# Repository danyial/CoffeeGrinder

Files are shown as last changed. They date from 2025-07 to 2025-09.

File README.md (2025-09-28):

# CoffeeGrinder

**Smart coffee grinder controller** with MQTT, OTA updates, and full Home Assistant integration.  
Includes 3D-printable housing, custom PCB (KiCad), and open-source firmware for ESP32.

---

## ✨ Features

- ☕️ Weight-based preset grinding
- 📡 MQTT auto-discovery (Home Assistant integration)
- 🌐 Web interface for configuration
- 🔧 Touch buttons for presets and calibration
- 📊 Live sensor telemetry and control
- 📦 STL files for 3D-printed case
- 🔌 KiCad schematics and PCB

---

## ⚙️ Cycloidal Drive (WIP)

This project uses a custom 3D-printed **cycloidal drive** to reduce the stepper motor's speed and increase torque.  
Currently, this mechanism is still under testing and may change in future iterations.

Contributions, feedback, and test results are welcome!

## 🖼️ Images

<p align="center">
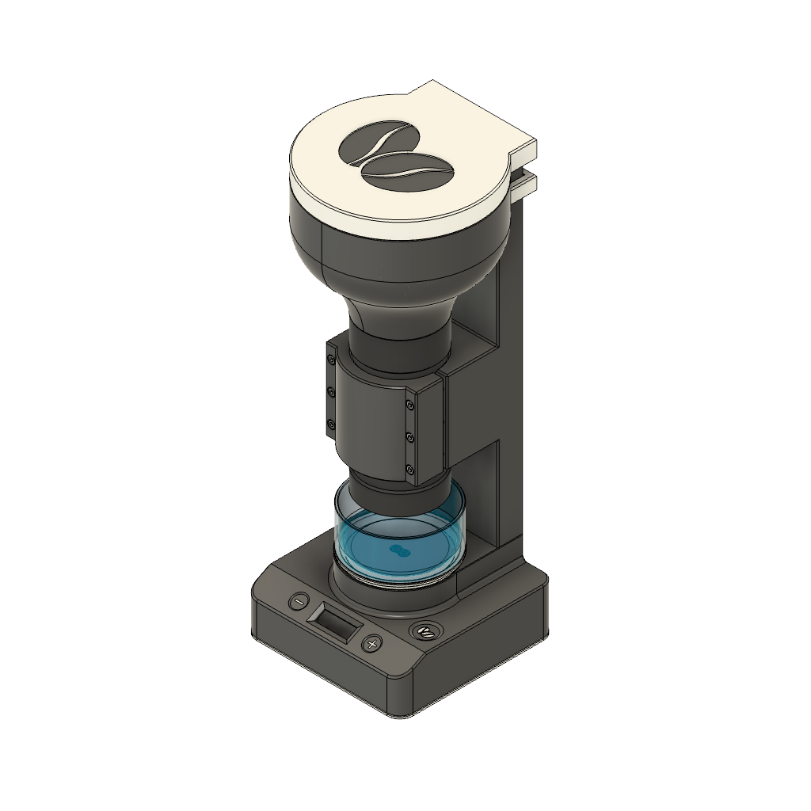
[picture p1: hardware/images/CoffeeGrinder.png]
CoffeeGrinder
  
  <br/>
  <em>CoffeeGrinder assembled</em>
</p>

<p align="center">
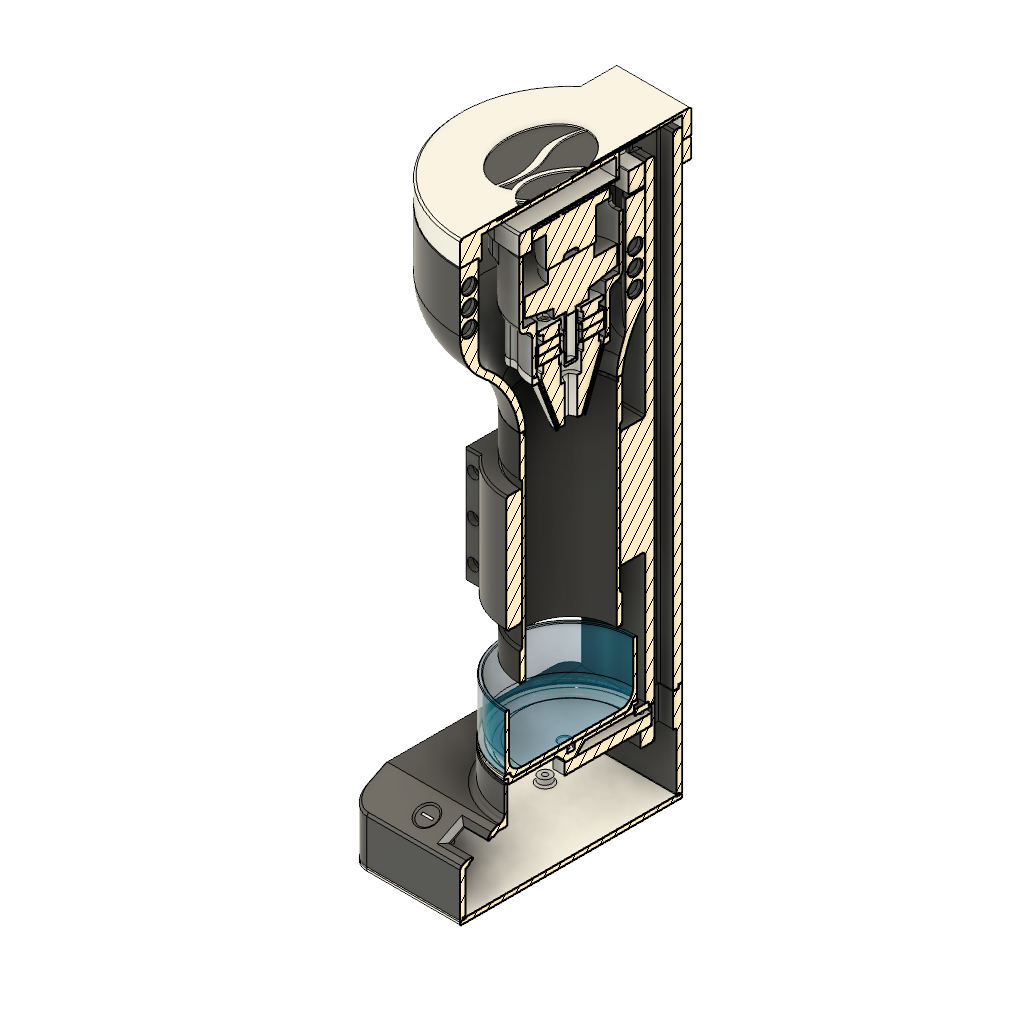
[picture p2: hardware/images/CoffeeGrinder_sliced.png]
CoffeeGrinder Sliced
  
  <br/>
  <em>Section view (sliced)</em>
</p>

<p align="center">
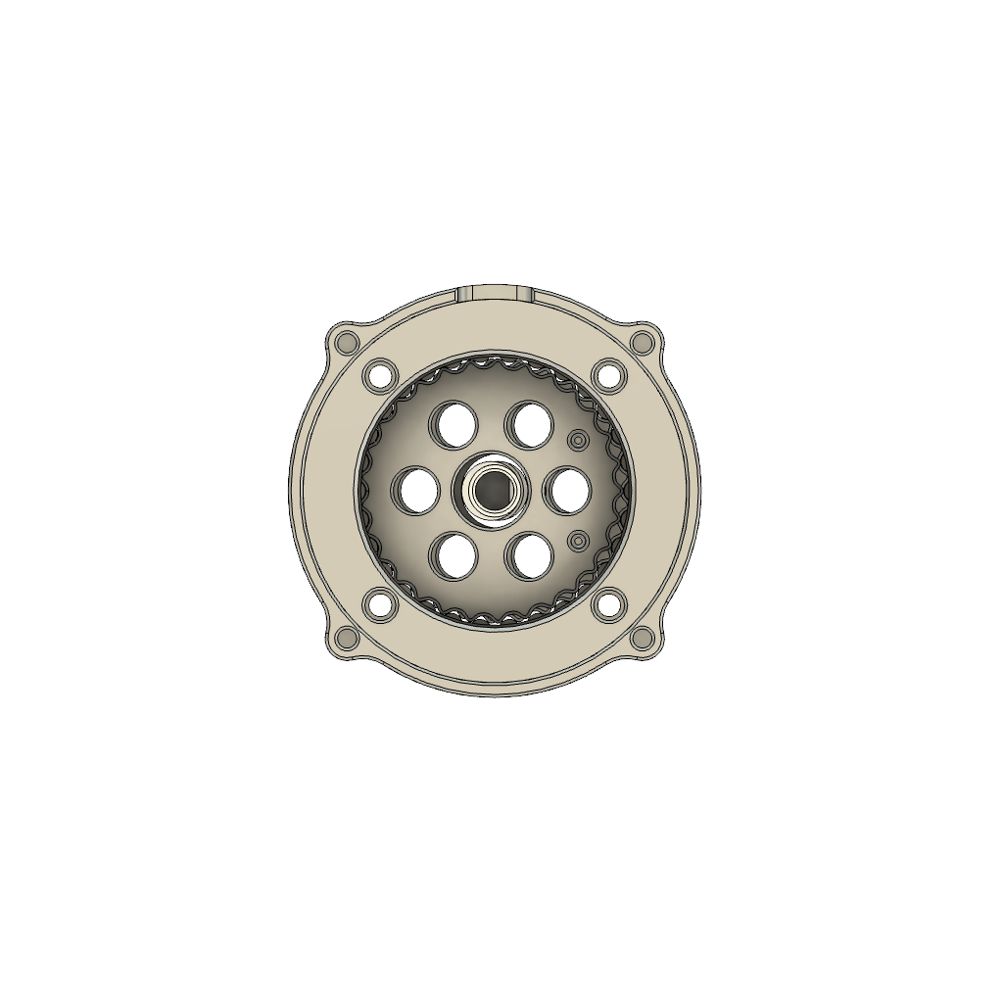
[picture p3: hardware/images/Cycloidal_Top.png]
Cycloidal Drive Top View
  
  <br/>
  <em>Cycloidal Drive Top View</em>
</p>

<p align="center">
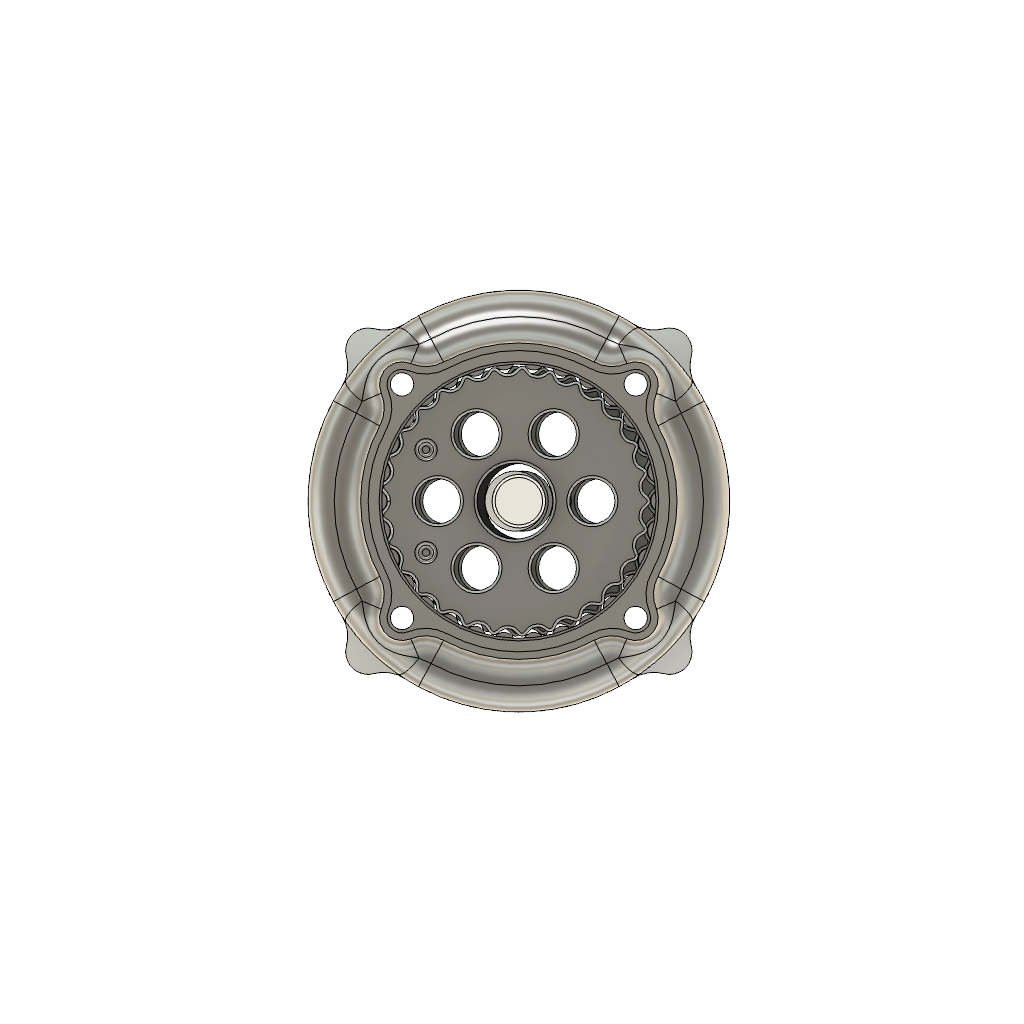
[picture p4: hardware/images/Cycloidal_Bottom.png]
Cycloidal Drive Bottom View
  
  <br/>
  <em>Cycloidal Drive Bottom View</em>
</p>

<p align="center">
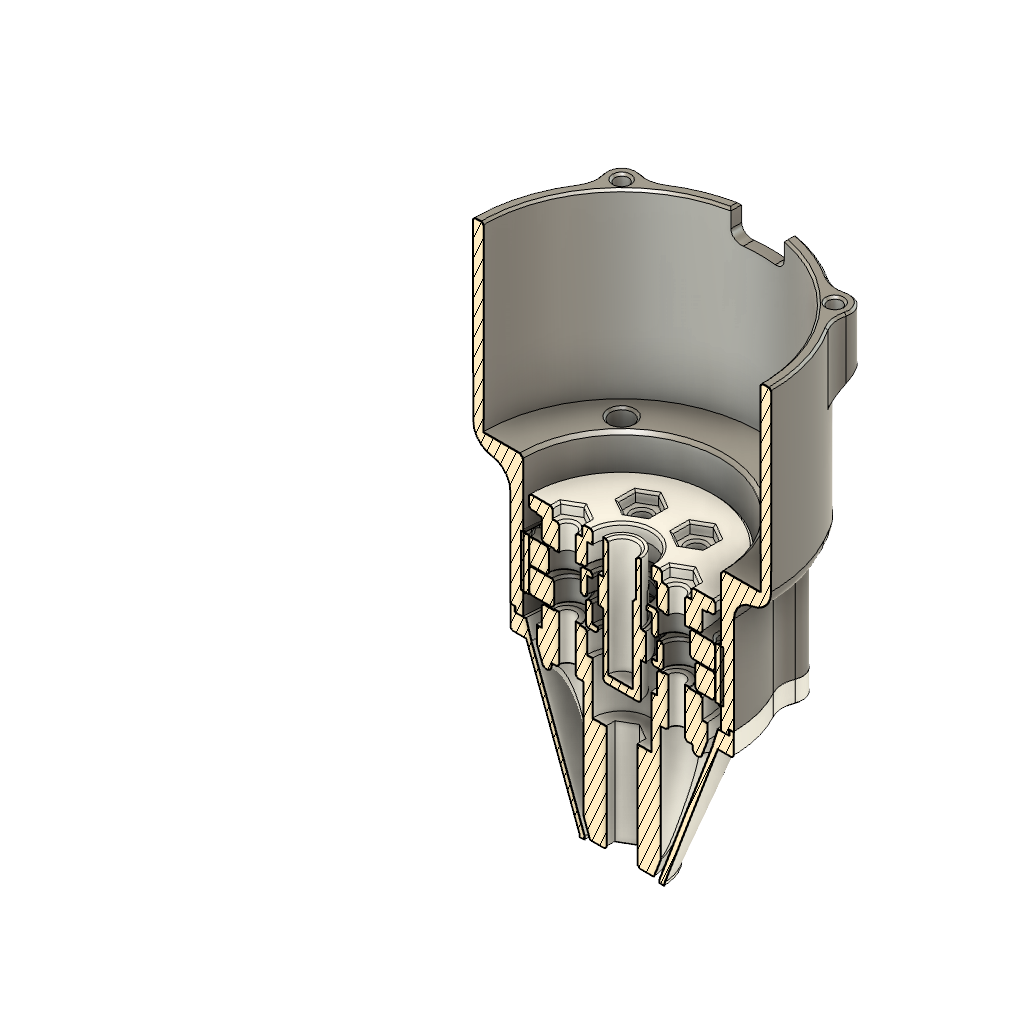
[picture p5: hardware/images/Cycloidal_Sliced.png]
Cycloidal Drive Sliced View
  
  <br/>
  <em>Cycloidal Drive Sliced View</em>
</p>

<p align="center">
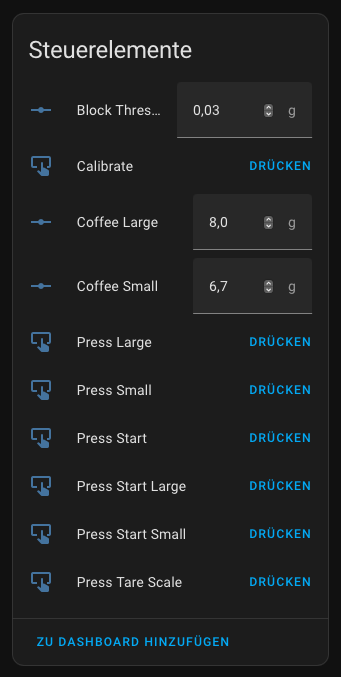
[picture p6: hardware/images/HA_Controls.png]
Home Assistant controls
  
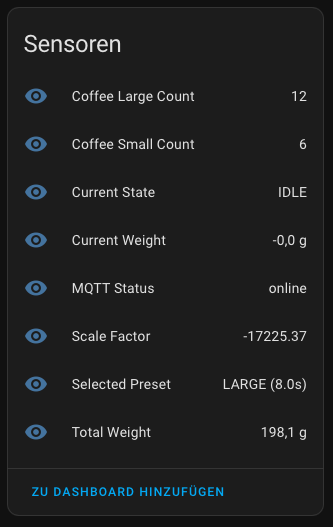
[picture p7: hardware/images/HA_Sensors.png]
Home Assistant sensors
  
  <br/>
  <em>Home Assistant</em>
</p>

---

## 📁 Project Structure

```text
CoffeeGrinder/
├── src/                # Firmware source code
├── include/            # Header files
├── lib/                # Custom libraries (optional)
├── data/               # Web interface (SPIFFS)
├── hardware/
│   ├── stl/            # 3D-printable case parts
│   ├── kicad/          # KiCad PCB project
│   ├── images/         # Project images
│   └── docs/           # Rendered schematics (PDF)
├── docs/               # General project documentation
├── LICENSE.md          # License (AGPL + CC BY-NC-SA)
└── README.md           # This file
```

---

## 🚀 Getting Started

## 🧾 Bill of Materials (BOM)

> **Note**: Some of the links below are affiliate links. If you make a purchase through them, I may receive a small commission at no extra cost to you. Thank you for your support!

- Manual Coffee Grinder [🛒 Amazon](https://amzn.to/4o6IfON)
- ESP32 Dev Board [🛒 Amazon](https://amzn.to/40CVtJ8)
- OLED Display [🛒 Amazon](https://amzn.to/44N8UZx)
- Step Down Converter [🛒 Amazon](https://amzn.to/4o4rhAz)
- HX711 Weight Sensor [🛒 Amazon](https://amzn.to/4lEH1bS)
- Scale [🛒 Amazon](https://amzn.to/3Uswbtt)
- 3x TTP223 Touch Sensors [🛒 Amazon](https://amzn.to/4133kje)
- 3x 10nF Capacitors [🛒 Amazon](https://amzn.to/3IF0UBf)
- Brushless Motor 5010 360KV [🛒 Amazon](https://amzn.to/3VFhHHp)
- ESC 35A or similar (BLHeli_s) - any ESC for brushless motors should work [🛒 Amazon](https://amzn.to/4mAlXCX)
- 2x Bearing 30x37x4 [🛒 Amazon](https://amzn.to/46XXUtu)
- 2x Bearing 8x12x3.5 [🛒 Amazon](https://amzn.to/3UtORsR)
- 2x Bearing 7x13x4 [🛒 Amazon](https://amzn.to/470tUxc)
- 6x Spacer [🛒 Amazon](https://amzn.to/4lLxm3v)
- 12x Magnets 7x2 [🛒 Amazon](https://amzn.to/4f6ZivV)
- Power Supply [🛒 Amazon](https://amzn.to/4o3DJ3y)
- Elko [🛒 Amazon](https://amzn.to/3Uhur6B)
- DC Connector [🛒 Amazon](https://amzn.to/4f7ja2e)
- some cables
- 2x M3x12 SHCS screws [🛒 Amazon](https://amzn.to/4lT12eP)
- 6x M3x16 SHCS screws [🛒 Amazon](https://amzn.to/4lT12eP)
- 6x M3x25 SHCS screws [🛒 Amazon](https://amzn.to/4lT12eP)
- 10x M3x30 SHCS screws [🛒 Amazon](https://amzn.to/4lT12eP)
- 10x M3 screws [🛒 Amazon](https://amzn.to/44Lvy4o)
- 8x M3 nuts [🛒 Amazon](https://amzn.to/4lT12eP)
- 2x M4x20 SHCS screws [🛒 Amazon](https://amzn.to/4lILPgh)
- 6x M3 Threaded Inserts [🛒 Amazon](https://amzn.to/474Kj3K)
- 2x M4 Threaded Inserts [🛒 Amazon](https://amzn.to/44OBxFI)

### Requirements

- MQTT Broker (e.g., Mosquitto)
- Home Assistant (optional, for integration)

### Flashing

Use [PlatformIO](https://platformio.org/) in VSCode:

---

## 🔧 Web Interface

Accessible after WiFi configuration.  
Use it to set:

- MQTT server credentials
- Calibration
- Preset values
- Start grinding manually

---

## 🧠 Home Assistant Integration

Entities auto-discovered via MQTT:

- Sensors: weight, selected preset, scale factor, total weight
- Numbers: block threshold, preset weights
- Buttons: start, calibrate, tare, run preset

Make sure `discovery` is enabled in your MQTT integration.

---

## 🔐 License

- Firmware: [AGPL-3.0](https://www.gnu.org/licenses/agpl-3.0.html)
- Hardware + STL: [CC BY-NC-SA 4.0](https://creativecommons.org/licenses/by-nc-sa/4.0/)

**© 2025 Danny Smolinsky**

For commercial licensing inquiries, contact the author.

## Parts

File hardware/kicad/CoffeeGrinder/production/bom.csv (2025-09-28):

Designator | Footprint | Quantity | Value | LCSC Part #
C1 | CP_Radial_D10.0mm_P7.50mm | 1 | C_Polarized
DISPLAY1 | JST_PH_B4B-PH-K_1x04_P2.00mm_Vertical | 1 | SSD1306
ESC_POWER1 | AMASS_XT30UPB-F_1x02_P5.0mm_Vertical | 1 | Conn_01x02
ESC_SIGNAL1 | JST_PH_B2B-PH-K_1x02_P2.00mm_Vertical | 1 | Conn_01x02_Pin
GRIND1, LED1, LEFT1, RIGHT1 | JST_PH_B3B-PH-K_1x03_P2.00mm_Vertical | 4 | Conn_01x03_Pin
HX711 | JST_PH_B4B-PH-K_1x04_P2.00mm_Vertical | 1 | Conn_01x04_Pin
LM2596 | YAAJ_DCDC_StepDown_LM2596 | 1 | YAAJ_DCDC_StepDown_LM2596
POWER_IN1 | AMASS_XT30UPB-M_1x02_P5.0mm_Vertical | 1 | Conn_01x02_Pin
U1 | ESP32-DevKitC | 1 | ESP32-DevKitC

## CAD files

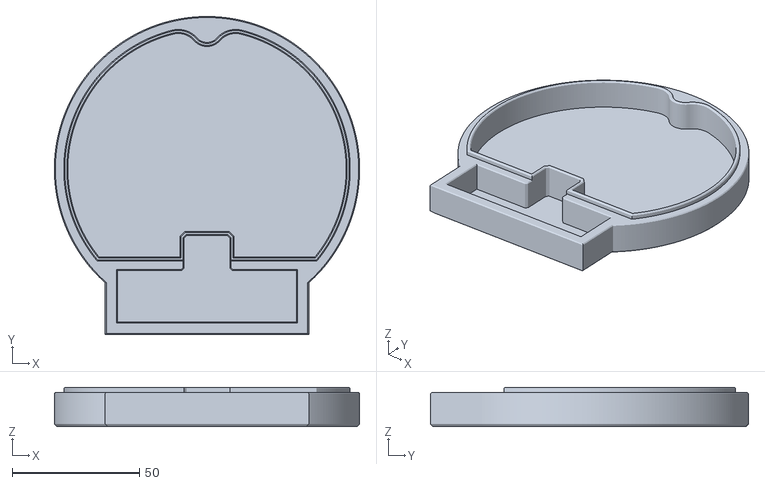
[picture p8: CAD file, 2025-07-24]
hardware/stl/Bean Bucket/Bean Bucked Lid.stl
120.0 x 125.0 x 15.4

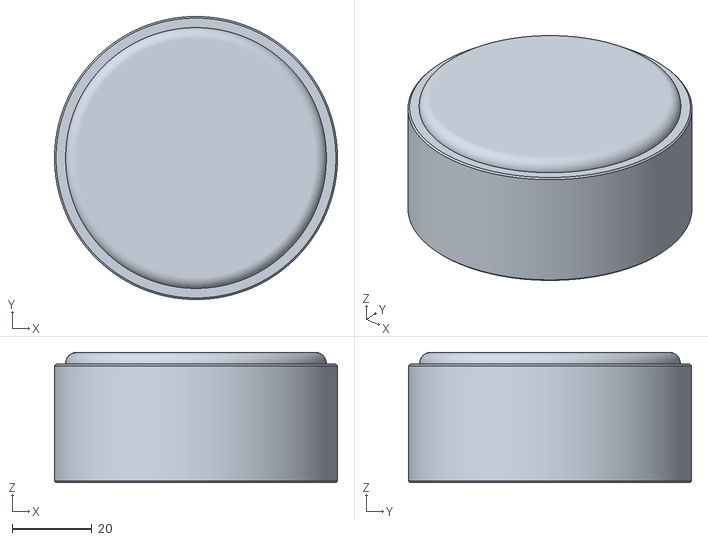
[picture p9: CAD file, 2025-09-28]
hardware/stl/Body/Bowl.stl
71.2 x 71.2 x 32.8

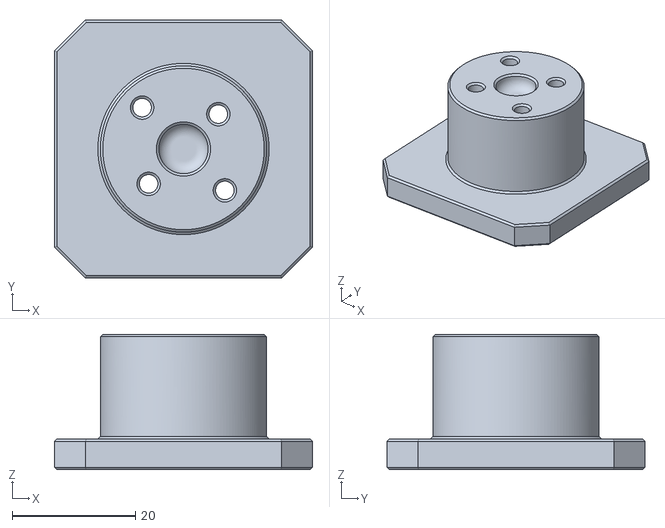
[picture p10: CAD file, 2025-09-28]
hardware/stl/Gear/Motor Mount.stl
41.9 x 41.9 x 22.0

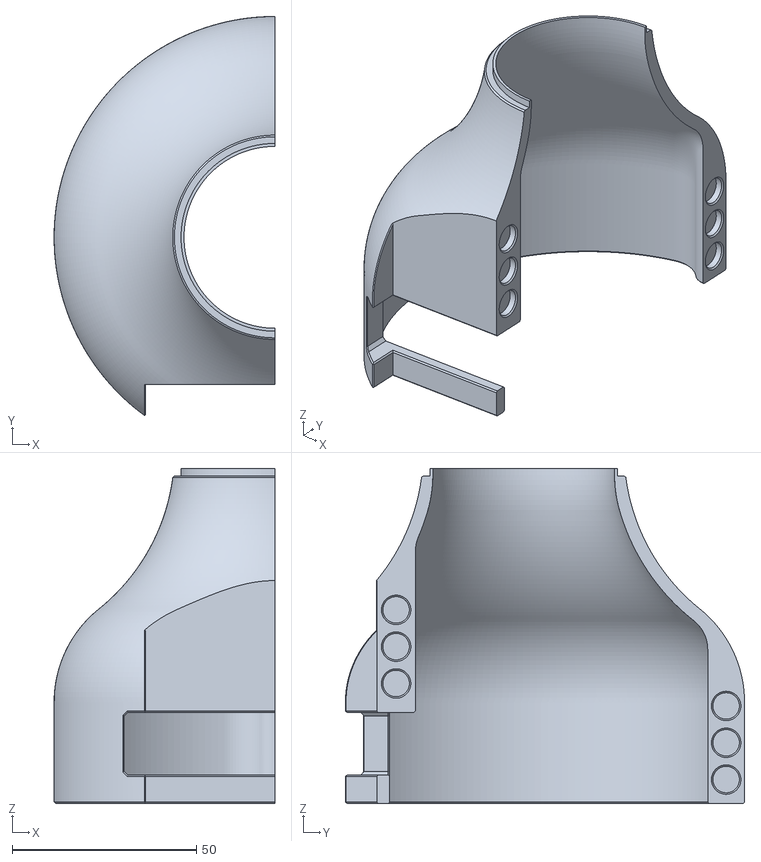
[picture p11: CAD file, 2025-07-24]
hardware/stl/Bean Bucket/Bean Bucket Left.stl
60.0 x 108.4 x 91.0

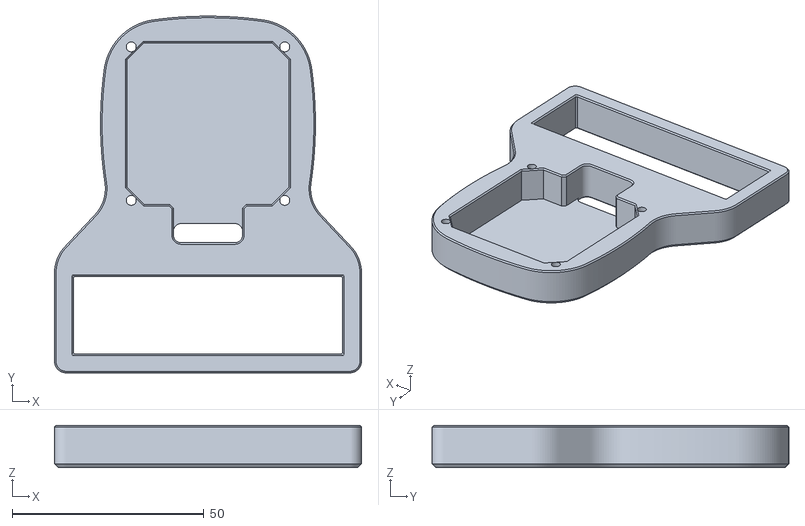
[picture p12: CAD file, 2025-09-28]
hardware/stl/Body/Stepper Fixing.stl
80.0 x 92.9 x 11.0

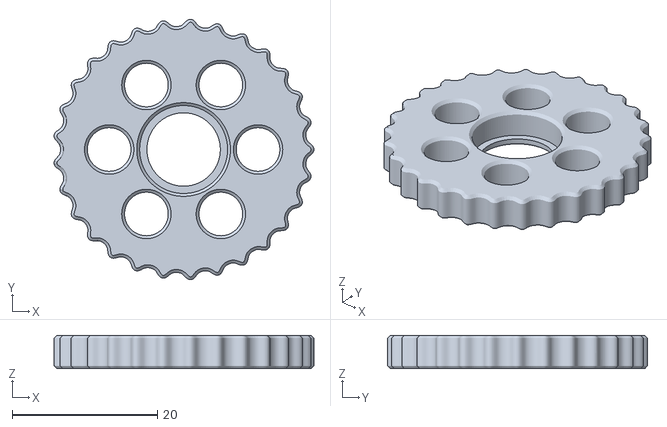
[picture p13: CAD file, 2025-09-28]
hardware/stl/Gear/Disk2 29.stl
35.8 x 35.8 x 4.60

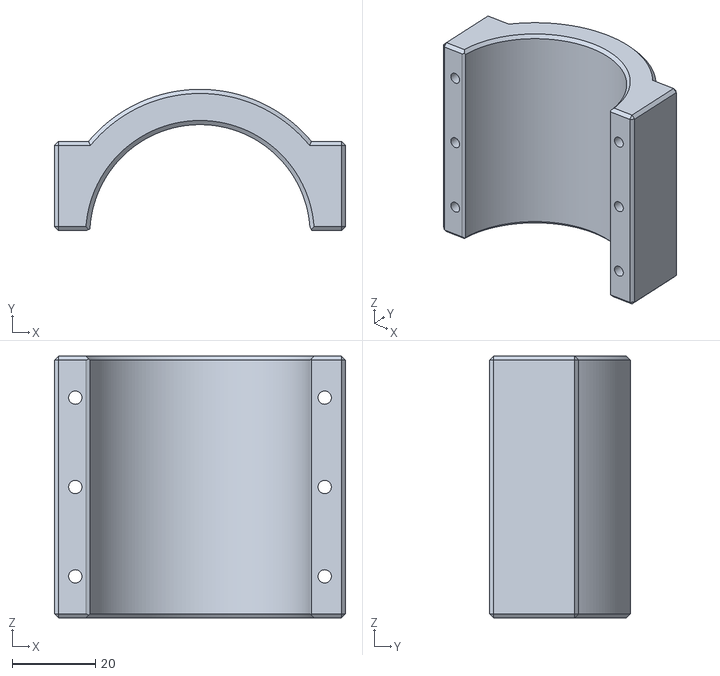
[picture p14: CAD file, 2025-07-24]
hardware/stl/Body/Grinder Holder Front.stl
70.0 x 34.0 x 63.0

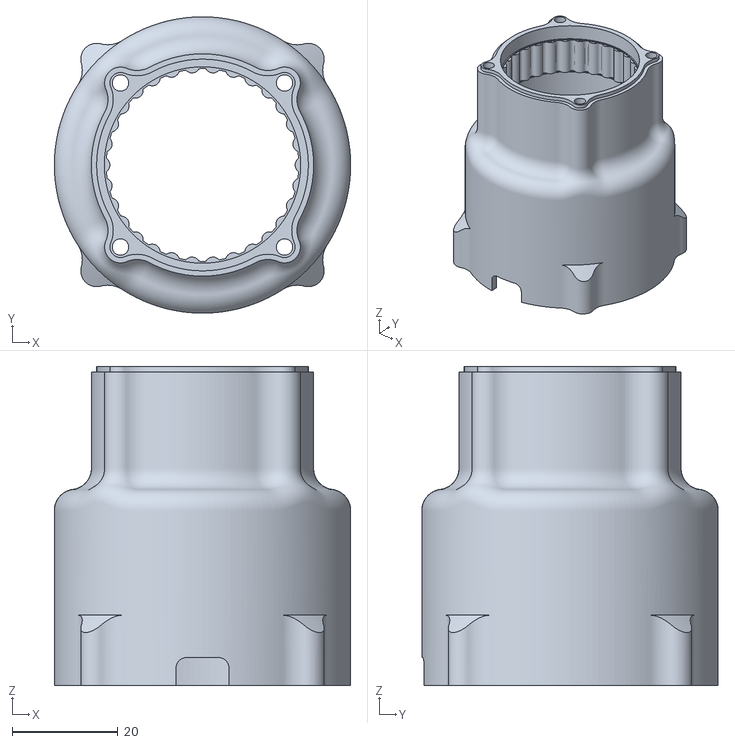
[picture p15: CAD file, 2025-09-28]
hardware/stl/Gear/Housing.stl
56.0 x 56.0 x 60.3

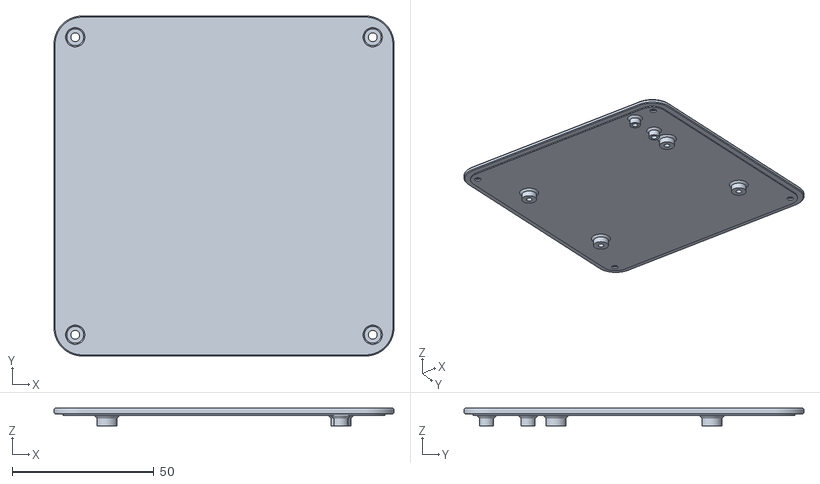
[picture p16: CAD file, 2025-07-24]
hardware/stl/Body/Bottom Plate.stl
120.0 x 120.0 x 6.20

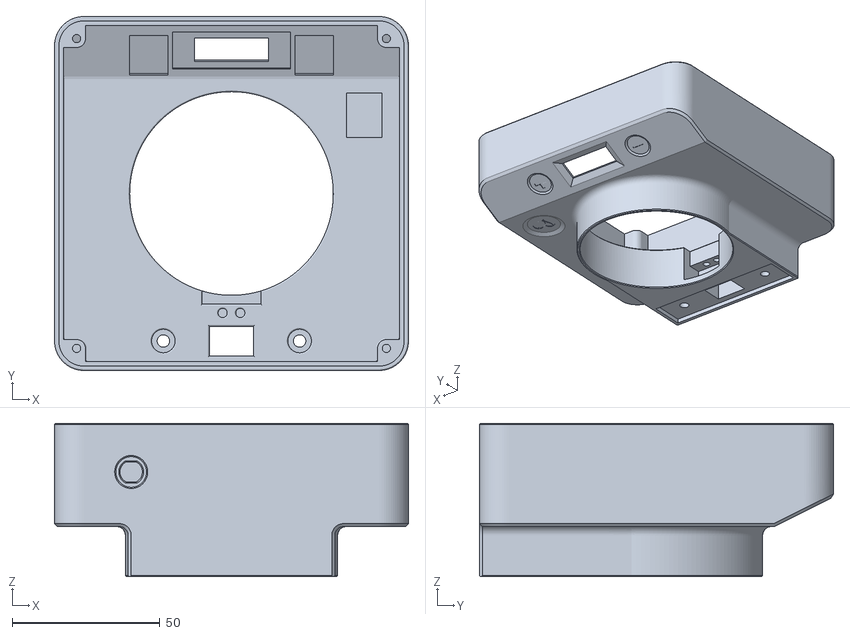
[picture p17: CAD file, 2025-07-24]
hardware/stl/Body/Body.stl
120.0 x 120.0 x 52.0

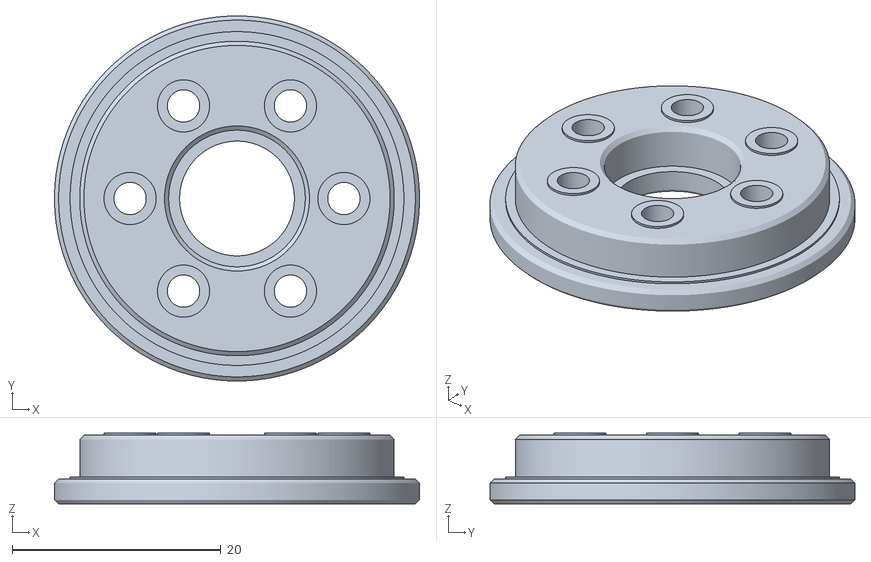
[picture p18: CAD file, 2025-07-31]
hardware/stl/Gear/Cap Top.stl
35.0 x 35.0 x 6.80

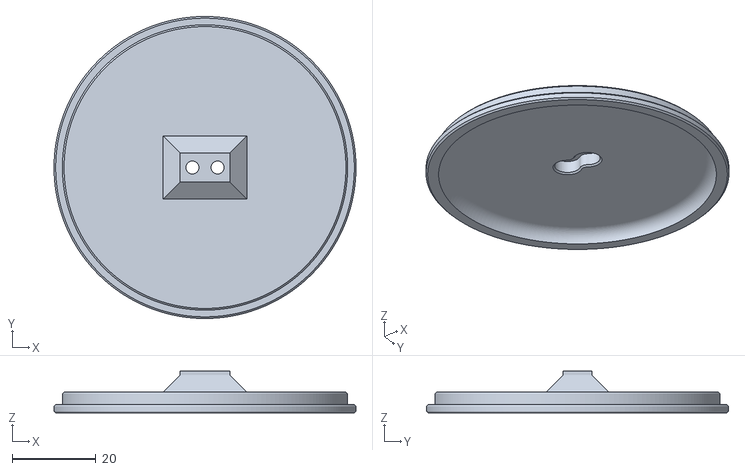
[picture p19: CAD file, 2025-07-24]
hardware/stl/Body/Table.stl
72.0 x 72.0 x 10.0

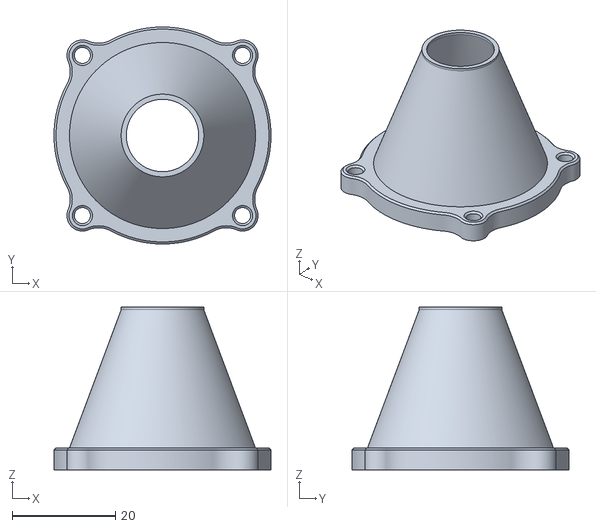
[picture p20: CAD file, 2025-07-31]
hardware/stl/Gear/Coupling Cover.stl
42.0 x 42.0 x 31.5

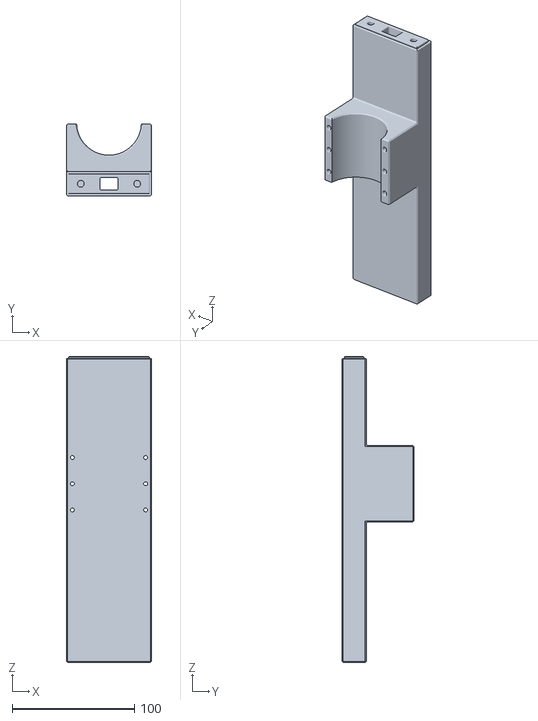
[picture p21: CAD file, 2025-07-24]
hardware/stl/Body/Grinder Holder Back.stl
70.0 x 59.0 x 250.8

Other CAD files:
hardware/stl/Bean Bucket/Bean Bucket Right.stl
hardware/stl/Gear/Disk1 29.stl
hardware/stl/Gear/Cap Bottom.stl
hardware/stl/Gear/Shaft.stl

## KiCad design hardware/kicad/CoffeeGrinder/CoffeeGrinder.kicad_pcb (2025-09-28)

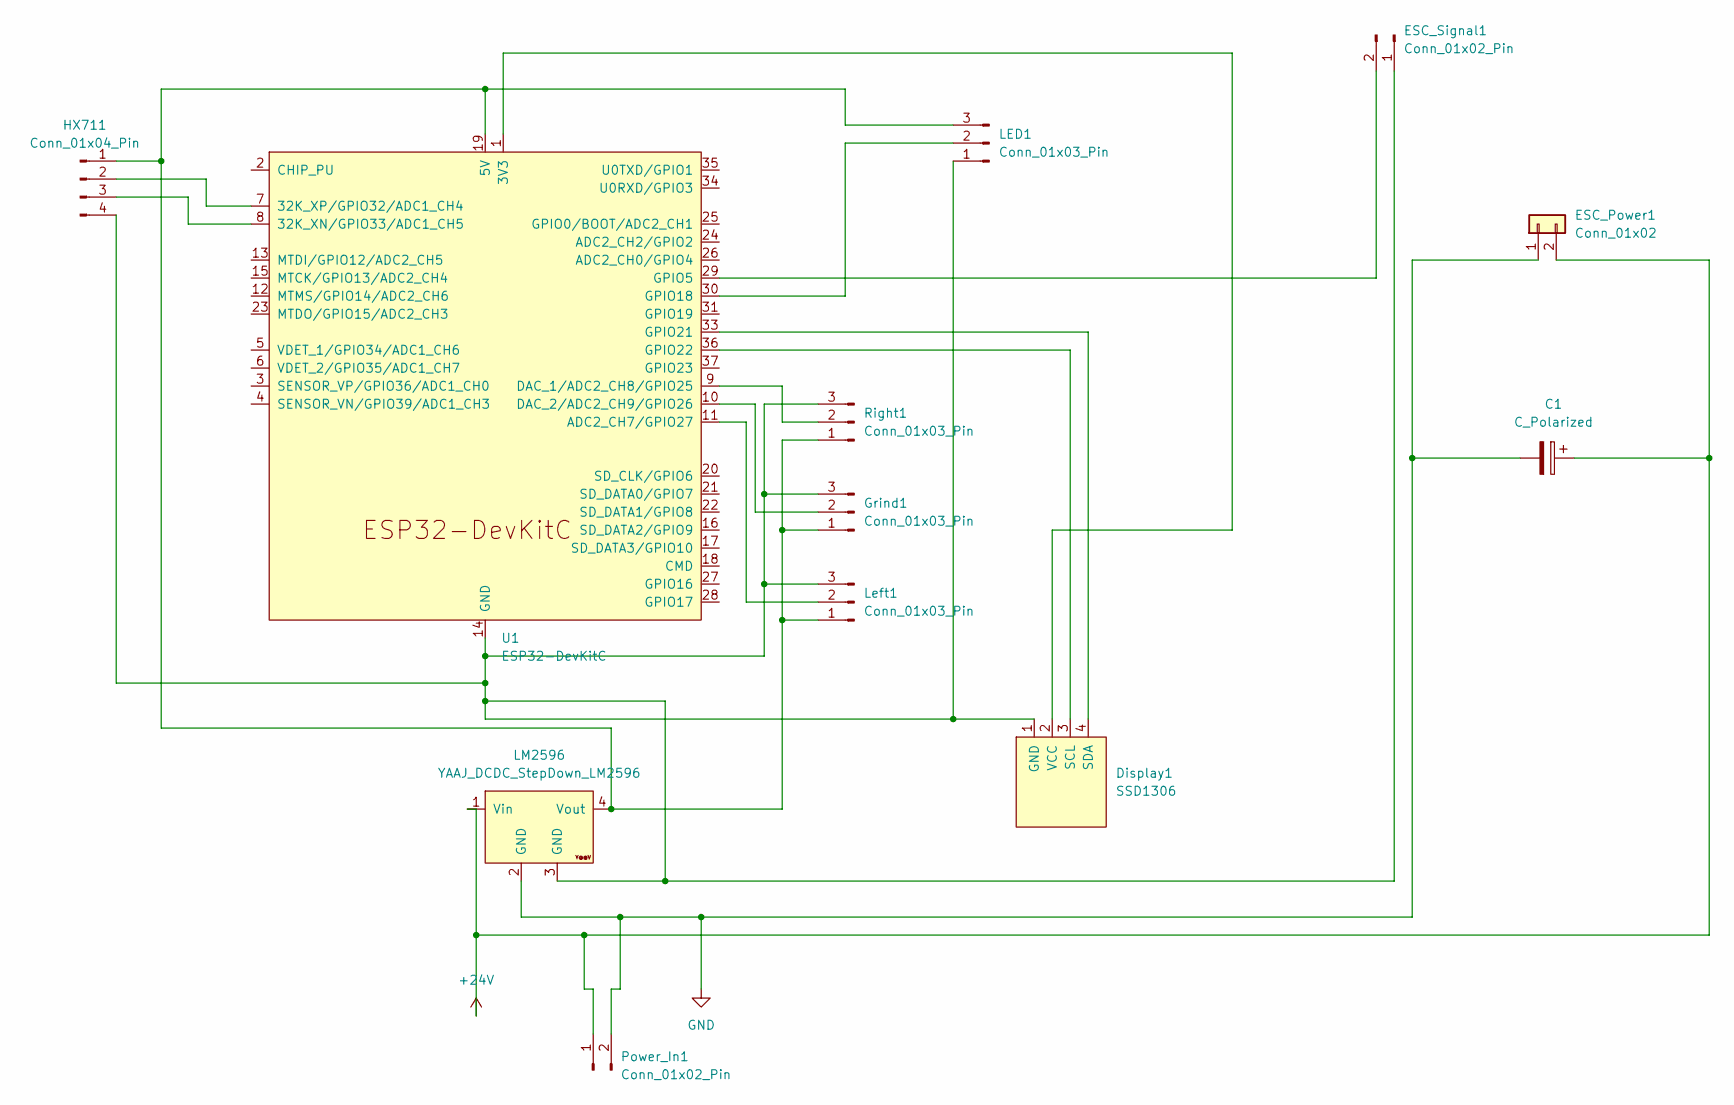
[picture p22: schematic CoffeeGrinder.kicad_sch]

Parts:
C1: C_Polarized; CP_Radial_D10.0mm_P7.50mm
Display1: SSD1306; JST_PH_B4B-PH-K_1x04_P2.00mm_Vertical
ESC_Power1: Conn_01x02; AMASS_XT30UPB-F_1x02_P5.0mm_Vertical
ESC_Signal1: Conn_01x02_Pin; JST_PH_B2B-PH-K_1x02_P2.00mm_Vertical
Grind1: Conn_01x03_Pin; JST_PH_B3B-PH-K_1x03_P2.00mm_Vertical
HX711: Conn_01x04_Pin; JST_PH_B4B-PH-K_1x04_P2.00mm_Vertical
LED1: Conn_01x03_Pin; JST_PH_B3B-PH-K_1x03_P2.00mm_Vertical
LM2596: YAAJ_DCDC_StepDown_LM2596
Left1: Conn_01x03_Pin; JST_PH_B3B-PH-K_1x03_P2.00mm_Vertical
Power_In1: Conn_01x02_Pin; AMASS_XT30UPB-M_1x02_P5.0mm_Vertical
Right1: Conn_01x03_Pin; JST_PH_B3B-PH-K_1x03_P2.00mm_Vertical
U1: ESP32-DevKitC

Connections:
+24V: C1.1, ESC_Power1.2, LM2596.1 (Vin), Power_In1.1
GND: C1.2, ESC_Power1.1, LM2596.2 (GND), Power_In1.2
unnamed: Display1.1 (GND), ESC_Signal1.1, Grind1.3, HX711.4, LED1.1, LM2596.3 (GND), Left1.3, Right1.3, U1.14 (GND), U1.32 (GND), U1.38 (GND)
unnamed: Display1.3 (SCL), U1.36 (GPIO22)
unnamed: Display1.4 (SDA), U1.33 (GPIO21)
unnamed: Display1.2 (VCC), U1.1 (3V3)
unnamed: ESC_Signal1.2, U1.29 (GPIO5)
unnamed: Grind1.1, HX711.1, LED1.3, LM2596.4 (Vout), Left1.1, Right1.1, U1.19 (5V)
unnamed: Grind1.2, U1.10 (DAC_2/ADC2_CH9/GPIO26)
unnamed: HX711.2, U1.7 (32K_XP/GPIO32/ADC1_CH4)
unnamed: HX711.3, U1.8 (32K_XN/GPIO33/ADC1_CH5)
unnamed: LED1.2, U1.30 (GPIO18)
unnamed: Left1.2, U1.11 (ADC2_CH7/GPIO27)
unnamed: Right1.2, U1.9 (DAC_1/ADC2_CH8/GPIO25)

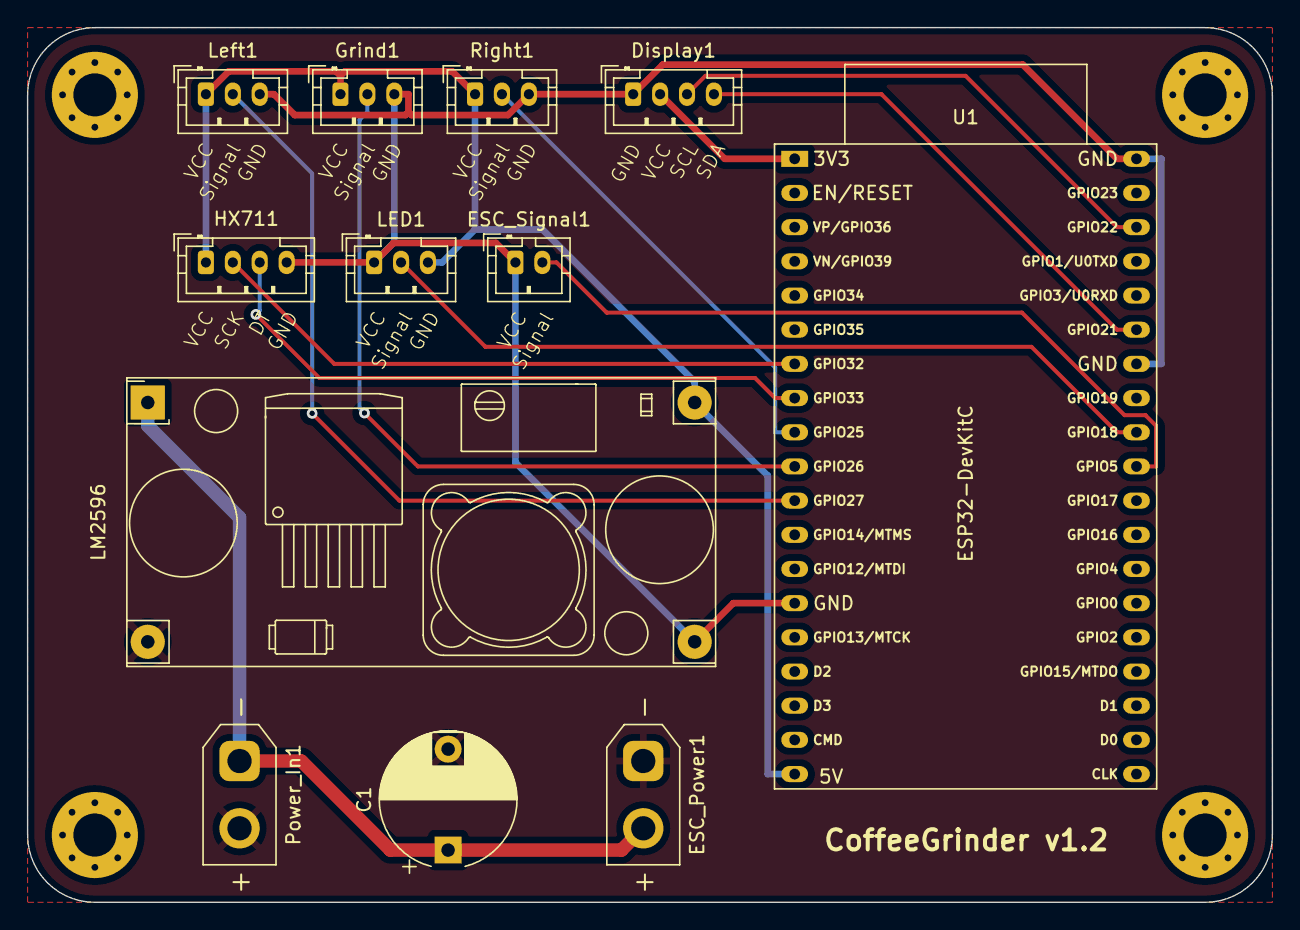
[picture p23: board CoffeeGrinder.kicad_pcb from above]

Board: 2 copper layers, 92.5 x 65.0 mm, 16 parts (0 on the bottom side), 14 nets.

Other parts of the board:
REF1, REF2, REF3, REF4: MountingHole_3.2mm_M3_Pad_Via

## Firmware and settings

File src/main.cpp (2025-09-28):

#include <Arduino.h>
#include <Bounce2.h>
#include <Preferences.h>
#include <WebServer.h>
#include <WiFi.h>
#include <Wire.h>

#include <Adafruit_GFX.h>
#include <Adafruit_SSD1306.h>
#include <DShotRMT.h>
#include <StreamString.h>
#include <esp_wifi.h>

#include <cstdarg>
#include <cstdio>
#include <vector>

#include "HX711.h"
#include "mqtt.h"
#include "ota.h"
#include "pins.h"
#include "types.h"
#include "webserver.h"

// -----------------------------------------------------------------------------
// Configuration constants
// -----------------------------------------------------------------------------

constexpr int8_t OLED_RESET = -1;
constexpr uint8_t SCREEN_ADDRESS = 0x3C;

constexpr unsigned long DISPLAY_REFRESH_MS = 50;
constexpr unsigned long SCALE_INTERVAL_MS = 500;
constexpr unsigned long DEBOUNCE_DELAY = 50;

constexpr uint16_t MIN_PRESET_WEIGHT = 1;
constexpr uint16_t MAX_PRESET_WEIGHT = 300;

constexpr uint16_t MOTOR_RUN_THROTTLE = 1200;
constexpr uint16_t MOTOR_SLOW_THROTTLE = MOTOR_RUN_THROTTLE / 2;
constexpr uint16_t MOTOR_RAMP_UP_STEP = 2;
constexpr uint16_t MOTOR_RAMP_UP_DELAY_MS = 4;
constexpr uint16_t MOTOR_RAMP_DOWN_STEP = 25;
constexpr uint16_t MOTOR_RAMP_DOWN_DELAY_MS = 4;
constexpr uint16_t MOTOR_RAMP_MIN_HOLD_MS = 200;
constexpr float MOTOR_SLOWDOWN_THRESHOLD_G = 0.7f;

const unsigned long LONGPRESS_MS = 2000;

// -----------------------------------------------------------------------------
// Logging
// -----------------------------------------------------------------------------

WiFiServer logServer(23);
std::vector<WiFiClient> clients;

#if ENABLE_LOGGING
static void purgeClients()
{
    for (auto it = clients.begin(); it != clients.end();)
    {
        if (!it->connected())
        {
            it->stop();
            it = clients.erase(it);
        }
        else
        {
            ++it;
        }
    }
}

void logPrint()
{
    Serial.println();
    purgeClients();
    for (auto &client : clients)
    {
        client.println();
    }
}

void logPrint(const String &msg)
{
    Serial.println(msg);
    purgeClients();
    for (auto &client : clients)
    {
        client.println(msg);
    }
}

void logPrint(const __FlashStringHelper *msg)
{
    logPrint(String(msg));
}

void logPrint(const char *msg)
{
    logPrint(String(msg));
}

void logPrintf(const char *fmt, ...)
{
    char buffer[256];
    va_list args;
    va_start(args, fmt);
    int len = vsnprintf(buffer, sizeof(buffer), fmt, args);
    va_end(args);

    if (len < 0)
    {
        return;
    }

    if (len >= static_cast<int>(sizeof(buffer)))
    {
        len = sizeof(buffer) - 1;
    }

    Serial.write(reinterpret_cast<const uint8_t *>(buffer), len);

    purgeClients();
    for (auto &client : clients)
    {
        client.write(reinterpret_cast<const uint8_t *>(buffer), len);
    }
}
#endif

// -----------------------------------------------------------------------------
// Hardware instances
// -----------------------------------------------------------------------------

Bounce2::Button btnStart, btnL, btnR;

Adafruit_SSD1306 display(128, 32, &Wire, OLED_RESET);

DShotRMT motor(PIN_ESC, dshot_mode_t::DSHOT300, false);
static volatile uint16_t throttleStream = DSHOT_THROTTLE_MIN;
static volatile bool stopPending = true;
static uint16_t motorCurrentThrottle = DSHOT_CMD_MOTOR_STOP;

HX711 scale;

// -----------------------------------------------------------------------------
// Runtime state
// -----------------------------------------------------------------------------

volatile State state = IDLE;

uint16_t presetSmall = 8;
uint16_t presetLarge = 12;
PresetSelection selectedPreset = SMALL;

Preferences prefs;

float scaleFactor = 1.0;

uint16_t remaining = 0;
unsigned long lastMillis = 0;
unsigned long lastScaleMillis = 0;

float weight = 0.0;
float lastWeight = 0.0;
unsigned long lastWeightChangeTime = 0;
float blockThreshold = 0.03f;

unsigned long presetSmallRuns = 0;
unsigned long presetLargeRuns = 0;
float totalWeight = 0.0;

bool webStart = false;

// -----------------------------------------------------------------------------
// Forward declarations
// -----------------------------------------------------------------------------

static void motorSendRaw(uint16_t value);
void motorRampTo(uint16_t targetThrottle, uint16_t stepSize, uint16_t delayMs);
inline void motorRampUp() { motorRampTo(MOTOR_RUN_THROTTLE, MOTOR_RAMP_UP_STEP, MOTOR_RAMP_UP_DELAY_MS); }
inline void motorRampDown() { motorRampTo(DSHOT_CMD_MOTOR_STOP, MOTOR_RAMP_DOWN_STEP, MOTOR_RAMP_DOWN_DELAY_MS); }

void setupButtons();
void setupMotor();

void setSelectedPreset(PresetSelection selection);
void setRemainingTime();
void setPreset(PresetSelection selection);
void setState(State s);
void tareScale();
void calibrateScale();
void startGrinding(bool tare);
void enterSetting(PresetSelection selection);
void adjustSetting(State s, int8_t delta);
void handleStartButton(Bounce2::Button button);
void handleButton(Bounce2::Button button, PresetSelection selection);

void loadPreferences();
void savePreferences();

void drawDisplay();
String stateToString(State s);
void logState();

void displayTask(void *pvParameters);
void scaleTask(void *pvParameters);
void mqttTask(void *pvParameters);
void throttleTask(void *pvParameters);

void setup();
void loop();

// -----------------------------------------------------------------------------
// Motor control
// -----------------------------------------------------------------------------

static void motorSendRaw(uint16_t value) {
    if (value == DSHOT_CMD_MOTOR_STOP) {
        motorCurrentThrottle = DSHOT_CMD_MOTOR_STOP;
        stopPending = true;
        throttleStream = DSHOT_THROTTLE_MIN; // Signal am Leben halten
        return;
    }
    uint16_t constrained = constrain(value, DSHOT_THROTTLE_MIN, DSHOT_THROTTLE_MAX);
    motorCurrentThrottle = constrained;
    throttleStream = constrained;
}

void motorRampTo(uint16_t targetThrottle, uint16_t stepSize, uint16_t delayMs)
{
    uint16_t currentThrottle = motorCurrentThrottle;
    uint16_t desired = targetThrottle;

    if (desired == DSHOT_CMD_MOTOR_STOP)
    {
        if (currentThrottle == DSHOT_CMD_MOTOR_STOP)
        {
            throttleStream = DSHOT_THROTTLE_MIN;
            return;
        }

        int32_t value = currentThrottle;
        int32_t step = stepSize ? stepSize : 1;
        while (value > DSHOT_THROTTLE_MIN)
        {
            value -= step;
            if (value < DSHOT_THROTTLE_MIN)
            {
                value = DSHOT_THROTTLE_MIN;
            }

            motorSendRaw(static_cast<uint16_t>(value));
            if (delayMs)
            {
                delay(delayMs);
            }
        }

        motorSendRaw(DSHOT_CMD_MOTOR_STOP);
        return;
    }

    if (desired < DSHOT_THROTTLE_MIN)
    {
        desired = DSHOT_THROTTLE_MIN;
    }

    if (currentThrottle == desired)
    {
        motorSendRaw(desired);
        return;
    }

    int32_t step = stepSize ? stepSize : 1;
    step = (desired > currentThrottle) ? step : -step;
    if (step == 0)
    {
        step = (desired > motorCurrentThrottle) ? 1 : -1;
    }

    int32_t value = currentThrottle;
    bool minHoldDone = false;

    while (value != desired)
    {
        value += step;

        if ((step > 0 && value > desired) || (step < 0 && value < desired))
        {
            value = desired;
        }

        if (value < DSHOT_THROTTLE_MIN)
        {
            value = DSHOT_THROTTLE_MIN;
        }

        motorSendRaw(static_cast<uint16_t>(value));

        if (!minHoldDone && value == DSHOT_THROTTLE_MIN && desired > DSHOT_THROTTLE_MIN && MOTOR_RAMP_MIN_HOLD_MS > 0)
        {
            delay(MOTOR_RAMP_MIN_HOLD_MS);
            minHoldDone = true;
        }

        if (delayMs)
        {
            delay(delayMs);
        }
    }
}

// -----------------------------------------------------------------------------
// Input hardware
// -----------------------------------------------------------------------------

// Configure button pins and debounce settings
void setupButtons()
{
    btnStart.attach(BTN_START, INPUT);
    btnStart.interval(DEBOUNCE_DELAY);
    btnStart.setPressedState(HIGH);

    btnR.attach(BTN_R, INPUT);
    btnR.interval(DEBOUNCE_DELAY);
    btnR.setPressedState(HIGH);

    btnL.attach(BTN_L, INPUT);
    btnL.interval(DEBOUNCE_DELAY);
    btnL.setPressedState(HIGH);
}

// Setup motor
void setupMotor()
{
    // Initialize the motor
    dshot_result_t result = motor.begin();
    if (result.success) {
        LOG("Motor initialized successfully");
    } else {
        printDShotResult(result);
    }
}

// -----------------------------------------------------------------------------
// Grinding workflow & state transitions
// -----------------------------------------------------------------------------

// Setter for selected preset without side effects
void setSelectedPreset(PresetSelection selection)
{
    selectedPreset = selection;
}

// Set remaining time based on selected preset
void setRemainingTime()
{
    LOGF("[REMAINING] %.1fg / %.1fg\n", presetSmall / 10.0, presetLarge / 10.0);
    remaining = (selectedPreset == SMALL) ? presetSmall : presetLarge;
}

void setPreset(PresetSelection selection)
{
    setSelectedPreset(selection);
    savePreferences();
    setState(IDLE);
    scale.tare();
}

// Setter for state variable with automatic logging
void setState(State s)
{
    state = s;
    logState();
}

void tareScale()
{
    LOG("Tare Scale");
    delay(500);
    scale.tare();
}

void calibrateScale()
{
    setState(CALIBRATE);

    LOG("== SCALE CALIBRATION ==");
    LOG("Remove all weight. Taring...");
    scale.tare();
    LOG("Place known weight (e.g. 100g) and press Start button.");
}

// Start grinding: reset timer, optionally tare scale and change state to RUNNING
void startGrinding(bool tare)
{
    if (state == IDLE && tare)
    {
        tareScale();
    }

    lastMillis = millis();
    setRemainingTime();
    setState(RUNNING);
}

// Enter setting mode for selected preset
void enterSetting(PresetSelection selection)
{
    setState(selection == SMALL ? SET_LEFT : SET_RIGHT);
}

// Adjust preset time in setting mode
void adjustSetting(State s, int8_t delta)
{
    if (s == SET_LEFT)
        presetSmall += delta;
    else
        presetLarge += delta;
    presetSmall = constrain(presetSmall, MIN_PRESET_WEIGHT, MAX_PRESET_WEIGHT);
    presetLarge = constrain(presetLarge, MIN_PRESET_WEIGHT, MAX_PRESET_WEIGHT);
}

// Handle button press for short and long press actions
void handleStartButton(Bounce2::Button button)
{
    static bool isSetWeighing = false;
    static bool isSetIdle = false;

    if (button.isPressed())
    {
        if (button.currentDuration() >= LONGPRESS_MS)
        {
            if (state == IDLE && !isSetIdle)
            {
                isSetWeighing = true;
                setState(WEIGHING);
                tareScale();
            }
            else if (state == WEIGHING && !isSetWeighing)
            {
                isSetIdle = true;
                setState(IDLE);
            }
        }
    }
    else if (button.released())
    {
        LOG("RELEASED");
        if (button.currentDuration() < LONGPRESS_MS)
        {
            LOG("SHORT");
            if (state == IDLE && !isSetIdle)
            {
                LOG("Start Grinding");
                startGrinding(true);
                lastWeight = weight;
            }
            else if (state == WEIGHING && !isSetWeighing)
            {
                tareScale();
            }
        }

        isSetIdle = false;
        isSetWeighing = false;
    }
}

void handleButton(Bounce2::Button button, PresetSelection selection)
{
    static bool isSetSettings = false;

    if (button.isPressed())
    {
        if (button.currentDuration() >= LONGPRESS_MS && !isSetSettings)
        {
            LOG("Enter Settings");
            isSetSettings = true;
            enterSetting(selection);
        }
    }

    if (button.released())
    {
        if (button.currentDuration() < LONGPRESS_MS)
        {
            LOG("Set Preset");
            setPreset(selection);
        }

        isSetSettings = false;
    }
}

// -----------------------------------------------------------------------------
// Preferences & persistence
// -----------------------------------------------------------------------------

// Load presets and selected preset from non-volatile storage
void loadPreferences()
{
    prefs.begin("coffee", false);

    presetSmall = prefs.getUShort("pL", 8 * 10);
    presetLarge = prefs.getUShort("pR", 12 * 10);

    LOGF("[PREFERENCES] %d / %d g\n", presetSmall, presetLarge);

    uint32_t sel = prefs.getUInt("sel", static_cast<uint32_t>(selectedPreset));
    selectedPreset = (sel <= LARGE) ? static_cast<PresetSelection>(sel) : SMALL;

    scaleFactor = prefs.getFloat("scale", 1.0);
    scale.set_scale(scaleFactor);

    totalWeight = prefs.getFloat("totalWeight", 0.0);
    presetSmallRuns = prefs.getULong("presetSmallRuns", 0);
    presetLargeRuns = prefs.getULong("presetLargeRuns", 0);
    blockThreshold = prefs.getFloat("blockThreshold", 0.3);

    prefs.end();
}

// Save presets and selected preset to non-volatile storage
void savePreferences()
{
    prefs.begin("coffee", false);

    prefs.putUShort("pL", presetSmall);
    prefs.putUShort("pR", presetLarge);
    prefs.putUInt("sel", static_cast<uint32_t>(selectedPreset));
    prefs.putFloat("scale", scaleFactor);
    prefs.putFloat("totalWeight", totalWeight);
    prefs.putULong("presetSmallRuns", presetSmallRuns);
    prefs.putULong("presetLargeRuns", presetLargeRuns);
    prefs.putFloat("blockThreshold", blockThreshold);

    prefs.end();

    setSelectedPreset(selectedPreset);
    setRemainingTime();
    drawDisplay();
}

// -----------------------------------------------------------------------------
// Display & logging
// -----------------------------------------------------------------------------

// Update OLED display based on current state
void drawDisplay()
{
    display.clearDisplay();
    char buf[32];
    switch (state)
    {
    case IDLE:
        sprintf(buf, "%4.1fg", (selectedPreset == SMALL ? presetSmall : presetLarge) / 10.0);
        break;
    case WEIGHING:
        sprintf(buf, "%4.1fg", weight);
        break;
    case RUNNING:
        // float weight = scale.get_units();
        sprintf(buf, "%4.1fg", (remaining / 10.0) - weight);
        break;
    case PAUSED:
        sprintf(buf, "%4.1fg", (remaining / 10.0) - weight);
        break;
    case MEASURING:
        sprintf(buf, "Warte...");
        break;
    case FINISHED:
        sprintf(buf, "Fertig!");
        break;
    case SAVING:
        sprintf(buf, "Gespeichert!");
        break;
    case SET_LEFT:
        sprintf(buf, "Setze Kl.: %4.1f%s", presetSmall / 10.0, "g");
        break;
    case SET_RIGHT:
        sprintf(buf, "Setze Gr.: %4.1f%s", presetLarge / 10.0, "g");
        break;
    case CALIBRATE:
        sprintf(buf, "Kalibrierung");
        break;
    case EMPTY:
        sprintf(buf, "Bohnen\nleer?");
        break;
    case UPDATING:
        sprintf(buf, "Update...");
        break;
    }

    int16_t x1, y1;
    uint16_t w, h;
    display.setTextSize(2);
    display.getTextBounds(buf, 0, 0, &x1, &y1, &w, &h);
    int16_t x = (display.width() - w) / 2;
    int16_t y = (display.height() - h) / 2;
    display.setCursor(x, y);
    display.setTextColor(SSD1306_WHITE);
    display.println(buf);
    display.display();
}

// Convert state enum to human-readable string
String stateToString(State s)
{
    switch (s)
    {
    case IDLE: return "IDLE";
    case RUNNING: return "RUNNING";
    case PAUSED: return "PAUSED";
    case MEASURING: return "MEASURING";
    case FINISHED: return "FINISHED";
    case SAVING: return "SAVING";
    case SET_LEFT: return "SET_LEFT";
    case SET_RIGHT: return "SET_RIGHT";
    case CALIBRATE: return "CALIBRATE";
    case UPDATING: return "UDATING";
    case EMPTY: return "EMPTY";
    case WEIGHING: return "WEIGHING";
    default: return "UNKNOWN";
    }
}

// Log current state, preset and remaining time
void logState()
{
    LOGF("[STATE] %s\n", stateToString(state));
    LOGF("[PRESET] %s\n", (selectedPreset == SMALL) ? "SMALL" : "LARGE");
    LOGF("[REMAINING] %.1fg\n", remaining / 10.0);
}

// -----------------------------------------------------------------------------
// FreeRTOS tasks
// -----------------------------------------------------------------------------

// FreeRTOS task to refresh the display periodically
void displayTask(void *pvParameters)
{
    (void)pvParameters;
    while (true)
    {
        drawDisplay();
        vTaskDelay(pdMS_TO_TICKS(DISPLAY_REFRESH_MS));
    }
}

void scaleTask(void *pvParameters)
{
    (void)pvParameters;
    while (true)
    {
        weight = scale.get_units();
        // LOGF("[SCALE - Task] %.2f g\n", weight);
        vTaskDelay(pdMS_TO_TICKS(200));
    }
}

void mqttTask(void *pvParameters)
{
    (void)pvParameters;
    while (true)
    {
        loopMqtt();
        mqttPublishState();
        vTaskDelay(pdMS_TO_TICKS(100));
    }
}

void throttleTask(void *) {
    const TickType_t interval = pdMS_TO_TICKS(1);
    while (true) {
        if (stopPending) {
            motor.sendThrottle(DSHOT_CMD_MOTOR_STOP); // Befehl einmal
            stopPending = false;
        } else {
            motor.sendThrottle(throttleStream);       // Idle oder Run
        }
        vTaskDelay(interval);
    }
}

// -----------------------------------------------------------------------------
// Arduino lifecycle
// -----------------------------------------------------------------------------
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
void loop()
{
    ArduinoOTA.handle();

    WiFiClient newClient = logServer.accept();
    if (newClient)
    {
        newClient.setNoDelay(true);
        clients.push_back(newClient);
    }

    unsigned long now = millis();

    btnStart.update();
    btnL.update();
    btnR.update();

    if (now - lastScaleMillis >= SCALE_INTERVAL_MS && state != CALIBRATE)
    {
        lastScaleMillis += SCALE_INTERVAL_MS;
        // LOGF("[SCALE - loop] %.2f g\n", weight);
    }

    switch (state)
    {
    case IDLE:
        motorRampDown();
        handleStartButton(btnStart);
        handleButton(btnL, SMALL);
        handleButton(btnR, LARGE);
        break;

    case RUNNING:
    {
        float gramsRemaining = (remaining / 10.0f) - weight;
        uint16_t targetThrottle = (gramsRemaining <= MOTOR_SLOWDOWN_THRESHOLD_G) ? MOTOR_SLOW_THROTTLE : MOTOR_RUN_THROTTLE;
        motorRampTo(targetThrottle, MOTOR_RAMP_UP_STEP, MOTOR_RAMP_UP_DELAY_MS);

        if (fabs(weight - lastWeight) > blockThreshold)
        {
            lastWeight = weight;
            lastWeightChangeTime = now;
        }

        if (now - lastWeightChangeTime >= 4000)
        {
            LOG("[EMPTY] Max time of weight not changing reached");
            setState(EMPTY);
        }
        else if (now - lastWeightChangeTime >= 500)
        {
            lastWeightChangeTime = now;
        }

        if (weight * 10 >= remaining)
        {
            motorRampDown();
            setState(MEASURING);
        }

        if (webStart)
        {
            webStart = false; // Skip first check after Web-Start
        }
        else if (btnStart.released())
        {
            setState(PAUSED);
        }
        break;
    }

    case MEASURING:
        delay(1000);
        if (weight * 10 >= remaining)
        {
            setState(FINISHED);
        }
        else
        {
            startGrinding(false);
        }
        break;

    case EMPTY:
    case PAUSED:
        motorRampDown();

        if (btnStart.fell())
        {
            startGrinding(false);
        }

        if (btnL.fell())
        {
            setSelectedPreset(SMALL);
            savePreferences();
            setRemainingTime();
            setState(IDLE);
        }

        if (btnR.fell())
        {
            setSelectedPreset(LARGE);
            savePreferences();
            setRemainingTime();
            setState(IDLE);
        }
        break;

    case FINISHED:
        motorRampDown();
        if (selectedPreset == SMALL)
        {
            presetSmallRuns++;
        }
        else
        {
            presetLargeRuns++;
        }
        totalWeight += weight;
        setState(SAVING);
        break;

    case SAVING:
        savePreferences();
        setRemainingTime();
        delay(1000);
        setState(IDLE);
        break;

    case SET_LEFT:
    case SET_RIGHT:
        if (btnL.fell())
        {
            adjustSetting(state, -1);
        }

        if (btnR.fell())
        {
            adjustSetting(state, 1);
        }

        if (btnStart.fell())
        {
            setState(SAVING);
        }
        break;

    case CALIBRATE:
        if (btnStart.fell())
        {
            long reading = scale.get_value(10);
            LOGF("Raw reading: %ld", reading);

            float known_weight = 10.92;
            float factor = static_cast<float>(reading) / known_weight;

            LOGF("Calibration factor set: %.2f\n", factor);

            scaleFactor = factor;
            scale.set_scale(scaleFactor);

            setState(SAVING);
        }
        break;

    case WEIGHING:
        handleStartButton(btnStart);
        break;
    }
}

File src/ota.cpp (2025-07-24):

#include "ota.h"

void setupOTA() {
    ArduinoOTA.setHostname("coffeegrinder");

    ArduinoOTA.onStart([]() {
        Serial.println("Start OTA update");
    });

    ArduinoOTA.onEnd([]() {
        Serial.println("\nEnd OTA update");
    });

    ArduinoOTA.onProgress([](unsigned int progress, unsigned int total) {
        Serial.printf("Progress: %u%%\r", (progress / (total / 100)));
    });

    ArduinoOTA.onError([](ota_error_t error) {
        Serial.printf("Error[%u]: ", error);
        if (error == OTA_AUTH_ERROR) Serial.println("Auth Failed");
        else if (error == OTA_BEGIN_ERROR) Serial.println("Begin Failed");
        else if (error == OTA_CONNECT_ERROR) Serial.println("Connect Failed");
        else if (error == OTA_RECEIVE_ERROR) Serial.println("Receive Failed");
        else if (error == OTA_END_ERROR) Serial.println("End Failed");
    });

    ArduinoOTA.begin();
    Serial.println("OTA Ready");
}

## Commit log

2025-07-24 Add KiCAD files
    [CoffeeGrinder.kicad_pcb, CoffeeGrinder.kicad_sch]
2025-07-24 Add STLs
    [Bean Bucked Lid.stl, Bean Bucket Left.stl, Bean Bucket Right.stl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]
2025-07-24 Add Gerber Production files
    [CoffeeGrinder.kicad_pcb, bom.csv, designators.csv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]
2025-07-26 Fix blockThreshold not saved
    [main.cpp]
2025-07-26 Add weighing functionality. Fix publish config for HA
    [main.cpp]
2025-07-31 Add new Cycloidal Drive
    [Cap Bottom.stl, Cap Top.stl, Cap.stl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]
2025-07-31 Fix: add scoped blocks in switch-case to prevent variable initialization warnings
    - Wrapped RUNNING case in braces to avoid "crosses initialization" warning
    - Improved stepper block detection logic using STEPPER_ROTATION
    - Ensured cleaner variable scope and safer direction handling
    [main.cpp]
2025-07-31 Update BOM
2025-09-28 Replace stepper motor with 5010 brushless motor 360KV
    [CoffeeGrinder.kicad_pcb, CoffeeGrinder.kicad_sch, Disk1 29.stl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]
2025-09-28 Add missing bowl STL
    [Bowl.stl]
2025-09-28 Add missing motor mount. Update images
    [Motor Mount.stl]
